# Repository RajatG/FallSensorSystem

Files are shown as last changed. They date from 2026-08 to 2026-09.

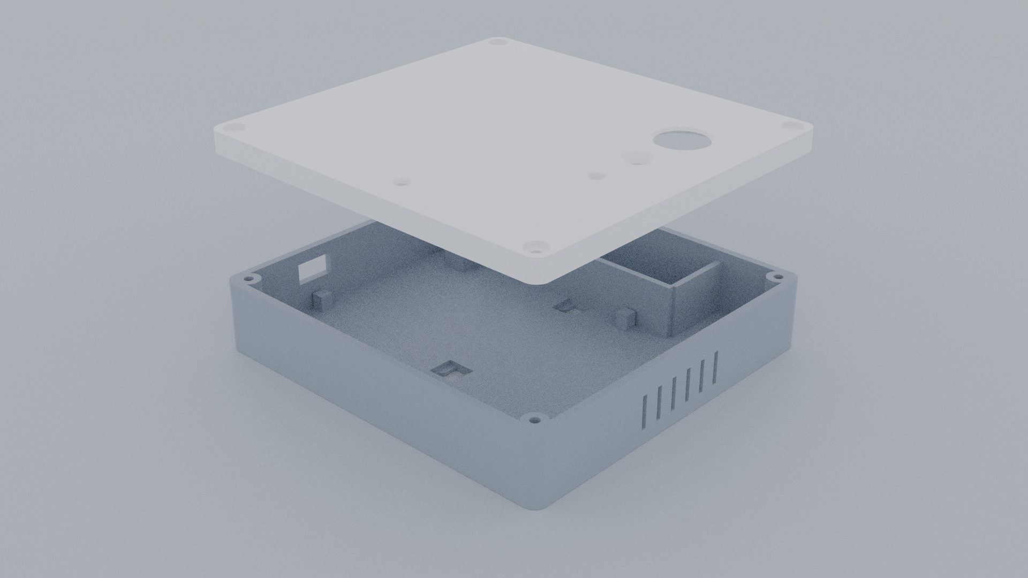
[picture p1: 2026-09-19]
enclosure/fall_sensor_enclosure_exploded.png

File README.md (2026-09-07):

# Fall Sensor System (IoT Firmware, KiCad PCB Hardware & Android Mobile App)

An ultra-low-power, dual-radar fall detection and room occupancy monitoring system engineered for ceiling and wall mounting with battery autonomy.

---

## 📁 Repository Overview

```
├── firmware/                        # Microcontroller & Radar Firmware
│   ├── fall_sensor_esp32_C1001_v1/  # ESP32 Firmware for C1001 60GHz Radar (v4.23)
│   ├── fall_sensor_esp32_ld2410_v1/ # ESP32 Firmware for LD2410 24GHz Radar (v4.23)
│   ├── fall_attiny_v1/              # ATtiny85 Low-Power Wake Sentinel (v4.8)
│   └── fall_attiny_mic_debug/       # ATtiny85 MIC Hardware Debug Utility
│
├── hardware/                        # KiCad 10.0 PCB & Schematic Files
│   ├── fall_sensor.kicad_sch        # Main System Schematic
│   ├── fall_sensor.kicad_pcb        # 2-Layer PCB Layout
│   ├── fall_sensor.kicad_pro        # KiCad Project Configuration
│   ├── FallSensor.kicad_sym     # Custom Symbol Library
│   ├── FallSensor.pretty/       # Custom Footprint Library
│   └── export/
│       ├── fall_sensor_gerbers.zip  # Production Gerber & Drill Package (JLCPCB/PCBWay)
│       └── pdf/                     # Printable Documentation (See hardware/export/pdf/README.md)
│           ├── fall_sensor_pcb_front_and_back_A4.pdf  # 1:1 True Scale Paper Testing Sheet
│           ├── fall_sensor_schematic_A4_printable.pdf # Printable A4 Schematic
│           ├── assembly/            # Top & Bottom Assembly Drawings
│           ├── layers/              # Top & Bottom Copper Layer Plots
│           └── schematic/           # Full-Size A3 Engineering Schematic
│
├── enclosure/                       # 3D Printed Wall-Mount Enclosure (v2.1 Square)
│   ├── fall_sensor_enclosure_base.stl # Base Mount with 18650 Battery Bay & PCB Standoffs
│   ├── fall_sensor_enclosure_lid.stl  # Front Cover with Apertures & Alignment Lip
│   ├── build_square_enclosure.py      # Parametric Blender Python CAD Script (v2.1)
│   ├── fall_sensor_enclosure.blend    # Master Blender CAD Project & Studio Renders
│   └── README.md                      # Mechanical Specifications & Slicer Guide
│
├── mobile_app/                      # Android Companion App (Jetpack Compose)
│   ├── app/                         # Source Code supporting C1001 & LD2410 Flavors
│   ├── build.gradle.kts
│   └── ...
│
└── docs/                            # Architectural Specs, Roadmaps & Engineering Docs (See docs/README.md)
    ├── README.md                    # Master Documentation Hub & Flow Map
    ├── Firmware_Architecture_and_Detection_Logic.md  # Complete Firmware Logic & 4-Layer Fall Pipeline
    ├── Master_4Stream_Roadmap_and_Recommendations.md # Comprehensive 4-Stream Status & Production Roadmap
    ├── PCB_Component_Connections_Verification.md     # Master 21-Component Netlist & Pinout Verification Guide
    ├── PCB_Component_Footprints_and_Dimensions.md    # Physical Dimensions, Drills & Pad Pitch Reference
    ├── SMD_BOM_Master_List.md       # Production SMD Component Master List (Rev B)
    ├── SMD_Hardware_Architecture.md # Power-path, Charger & Protection Circuitry Specs
    ├── C1001_Early_Exit_Analysis.md # Radar Optimization & Timing Breakdown
    └── ATtiny85_MIC_Analysis.md     # Sentinel Threshold & Acoustic Filter Specs
```

---

## ⚡ System Overview & Architecture

### What the System Is
The **Fall Sensor System** is a privacy-first, contactless room occupancy and fall detection device designed for elder care and clinical environments. It eliminates the need for cameras, audio-recording microphones, or wearable pendants.

### How it Works: The Staged-Wakeup Architecture
Operating mmWave radar continuously requires 60–120 mA, which would exhaust a battery in under two days. To achieve long battery life on a single 18650 cell, the system uses an **asymmetric staged-wakeup architecture**:

```
+-----------------------------------------------------------------------------------+
| 1. PASSIVE SENSING (Continuous ~35uA Draw)                                        |
|    - AM312 PIR watches for motion cone entry.                                     |
|    - LM393 acoustic sensor watches for mechanical floor impact shockwaves.       |
|    - ATtiny85 Sentinel debounces signals while ESP32 and Radar sleep.             |
+-----------------------------------------+-----------------------------------------+
                                          | Valid Motion or Thud Pulse
                                          v
+-----------------------------------------------------------------------------------+
| 2. RADAR VERIFICATION SNAPSHOT (2.5s - 4.0s Window)                               |
|    - ESP32 wakes from deep sleep and gates Radar power via MOSFET switch.         |
|    - mmWave Radar measures distance, target velocity, and floor-level coordinates.|
+-----------------------------------------+-----------------------------------------+
                                          |
                      +-------------------+-------------------+
                      |                                       |
              [ Normal Upright Motion ]               [ Confirmed Fall ]
                      |                                       |
                      v                                       v
+---------------------------------------------+ +-----------------------------------+
| 3. SMART EARLY EXIT                         | | 4. IMMEDIATE ALERTING             |
|    - Target confirmed standing/walking.     | |    - Red Fall Siren LED activates.|
|    - Radar cuts power at 2.5s - 4.0s.       | |    - BLE alert packet transmitted |
|    - BLE occupancy status updated.          | |      to Android caregiver app.    |
|    - ESP32 returns to deep sleep (<15uA).   | |    - Persists until recovery or   |
|      (Saves ~90% energy per event)          | |      manual sync button reset.    |
+---------------------------------------------+ +-----------------------------------+
```

---

## 📦 Engineering Streams & Subunit Documentation

The system is organized into four self-contained, documented engineering streams:

| Stream | Subunit Directory | Key Deliverables & Documentation |
|---|---|---|
| **⚡ Firmware** | [`firmware/`](firmware/README.md) | ESP32 C1001 & LD2410 drivers, ATtiny85 wake sentinel, v4.23 Gradual Posture Collapse detection, and flashing guides. |
| **🔌 Hardware (PCB)** | [`hardware/`](hardware/README.md) | KiCad 10.0 schematics, 2-layer PCB ($100 \times 80\text{ mm}$), pin mapping table, Gerbers, and 1:1 scale printable test sheets. |
| **🖨️ 3D Enclosure** | [`enclosure/`](enclosure/README.md) | v2.1 Square CAD model ($116.8 \times 110.8 \times 31.4\text{ mm}$), 18650 battery cradle, STL meshes, slicer settings, and photorealistic renders. |
| **📱 Mobile App** | [`mobile_app/`](mobile_app/README.md) | Android companion application (Jetpack Compose, Kotlin, BLE GATT), telemetry parser, and build flavor instructions. |
| **📚 Documentation** | [`docs/`](docs/README.md) | Master documentation hub, 4-layer fall logic specification, radar early exit analysis, acoustic sensitivity analysis, and SMD Rev B migration roadmap. |

---

## 🚀 Quick Manufacturing & Test Links

* **PCB Fabrication Gerbers:** [`hardware/export/fall_sensor_gerbers.zip`](hardware/export/fall_sensor_gerbers.zip) (Ready for JLCPCB/PCBWay upload).
* **1:1 Scale Paper Test Sheet:** [`hardware/export/pdf/fall_sensor_pcb_front_and_back_A4.pdf`](hardware/export/pdf/fall_sensor_pcb_front_and_back_A4.pdf) (For physical component fitting).
* **3D Printable STLs:** [`enclosure/fall_sensor_enclosure_base.stl`](enclosure/fall_sensor_enclosure_base.stl) and [`enclosure/fall_sensor_enclosure_lid.stl`](enclosure/fall_sensor_enclosure_lid.stl).
* **1:1 Scale 3D PCB Test Plate:** [`enclosure/fall_sensor_pcb_dummy.stl`](enclosure/fall_sensor_pcb_dummy.stl) (True KiCad 3D mesh with all 186 through-hole drill cutouts for physical pin-alignment and base cavity test-fitting).

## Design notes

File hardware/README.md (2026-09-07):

# 🔌 Hardware CAD & PCB Engineering (KiCad 10.0)

This directory contains the complete electronic schematic and PCB design files for the Fall Sensor System prototype (Rev A).

---

## 📁 Hardware Files

| File / Folder | Type | Description |
|---|:---:|---|
| **[`fall_sensor.kicad_sch`](fall_sensor.kicad_sch)** | Schematic | Main system schematic in KiCad 10 format. |
| **[`fall_sensor.kicad_pcb`](fall_sensor.kicad_pcb)** | PCB Layout | 2-layer, $100.00 \times 80.00\text{ mm}$ printed circuit board layout. |
| **[`fall_sensor.kicad_pro`](fall_sensor.kicad_pro)** | Project Config | KiCad project workspace and design rules. |
| **[`FallSensor.kicad_sym`](FallSensor.kicad_sym)** | Symbol Library | Custom schematic symbols for breakout modules. |
| **[`FallSensor.pretty/`](FallSensor.pretty/)** | Footprint Library | Custom PCB footprints for daughterboards and sensors. |
| **[`export/`](export/)** | Production Files | Manufacturing Gerbers and printable PDF packages. |

---

## 📐 PCB Specifications

* **Board Dimensions:** $100.00\text{ mm} \times 80.00\text{ mm}$
* **Layer Count:** 2-Layer FR4 ($1.6\text{ mm}$ thickness, $1\text{ oz}$ / $35\mu\text{m}$ copper)
* **Design Rule Status:** **0 DRC Errors, 0 Unconnected Nets**
* **Power Architecture:** Dual switched rails (Protected Li-Ion Battery $\rightarrow$ 5.0V Boost $\rightarrow$ 3.3V Step-Down).
* **Radar Gating:** High-side/low-side N-Channel MOSFET load switch controlled via GPIO 27.

---

## 📌 Microcontroller Pinout & Net Mapping

### ESP32 DevKit V1 (30-Pin) Net Connections
| Pin # | Label | Connected Net | Hardware Destination & Role |
|:---:|---|---|---|
| **1** | `3V3` | `+3V3` | Regulated 3.3V power input from U7 buck converter |
| **5** | `GPIO34` | `/BATT_ADC` | Midpoint of 100kΩ/100kΩ battery sensing divider |
| **8** | `GPIO33` | `Net-(U1-GPIO33)` | Tactile Sync & Alarm Clear Button (`SW1`) |
| **9** | `GPIO25` | `/PRESENCE` | C1001 radar hardware presence flag (`OUT1`) |
| **10** | `GPIO26` | `/FALL` | C1001 radar hardware fall detection flag (`OUT2`) |
| **11** | `GPIO27` | `/RADAR_EN` | Load switch gate control (energizes radar power rail) |
| **14** | `GND` | `GND` | Common system ground plane |
| **15** | `GPIO13` | `/PIR_WAKE` | Motion wake interrupt from ATtiny85 Sentinel (`PB2`) |
| **19** | `GPIO19` | `Net-(U1-GPIO19)` | Status Fall Alarm LED (`D1`) via 270Ω resistor |
| **26** | `GPIO17` | `/RADAR_RX` | Hardware UART RX $\leftarrow$ C1001 radar TX |
| **27** | `GPIO16` | `/RADAR_TX` | Hardware UART TX $\rightarrow$ C1001 radar RX |
| **28** | `GPIO4` | `/MIC_WAKE` | Acoustic impact wake interrupt from ATtiny85 Sentinel (`PB0`) |

### ATtiny85 Sentinel Pin Mapping
| Pin # | Label | Connected Net | Hardware Destination & Role |
|:---:|---|---|---|
| **2** | `PB4` | `Net-(U2-P4)` | Digital acoustic trigger input from LM393 (`DO`) |
| **5** | `PB1` | `Net-(PIR1-OUT)` | Digital motion trigger input from AM312 PIR (`OUT`) |
| **6** | `PB0` | `/MIC_WAKE` | Active-HIGH 50ms wake pulse to ESP32 `GPIO4` |
| **4** | `PB2` | `/PIR_WAKE` | Active-HIGH 50ms wake pulse to ESP32 `GPIO13` |
| **7** | `GND` | `GND` | Common ground |
| **8** | `VIN` | *Unconnected* | Bypassed (Digispark onboard regulator not used) |
| **9** | `5V/VCC` | `+3V3` | Regulated 3.3V power input from U7 buck converter |

---

## 📦 Manufacturing & Test Deliverables

* **Gerber Package:** [`export/fall_sensor_gerbers.zip`](export/fall_sensor_gerbers.zip) — Ready for direct upload to JLCPCB, PCBWay, or OSH Park.
* **1:1 True Scale Paper Testing Sheet:** [`export/pdf/fall_sensor_pcb_front_and_back_A4.pdf`](export/pdf/fall_sensor_pcb_front_and_back_A4.pdf) — Verified 1:1 A4 sheet with 10.0 cm calibration ruler for physical component fit-testing.
* **Assembly & Layer Drawings:** See [`export/pdf/README.md`](export/pdf/README.md) for top/bottom silkscreen and layer plots.

---

## 📖 Detailed Engineering References
* Complete 21-component netlist and verification tables: [`../docs/PCB_Component_Connections_Verification.md`](../docs/PCB_Component_Connections_Verification.md)
* Physical package outlines, drill sizes, and pad-to-pad pitches: [`../docs/PCB_Component_Footprints_and_Dimensions.md`](../docs/PCB_Component_Footprints_and_Dimensions.md)
* Production SMD Component Master List (Rev B): [`../docs/SMD_BOM_Master_List.md`](../docs/SMD_BOM_Master_List.md)

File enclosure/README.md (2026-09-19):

# 🖨️ Fall Sensor System - Wall-Mount 3D Printed Enclosure

This directory contains the complete **3D CAD engineering stream** for the Wall-Mounted Enclosure of the Fall Sensor System.

---

## 📁 Files in this Directory

| File | Type | Description |
|---|---|---|
| [`fall_sensor_enclosure_base.stl`](fall_sensor_enclosure_base.stl) | 3D Mesh (STL) | **Base Mount (v2.1)**: Integrated 79.5mm 18650 battery compartment with wire notch, retaining end-wall, open PIR alcove, 5mm PCB shelf posts, 4 corner screw bosses, rear wall-mount keyholes, USB-C port, and side ventilation louvers. |
| [`fall_sensor_enclosure_lid.stl`](fall_sensor_enclosure_lid.stl) | 3D Mesh (STL) | **Front Cover (v2.1)**: Balanced square profile with 4 corner screw guide pillars, 4 downward PCB clamping tabs (3.9mm), PIR dome opening, Radar RF thin window, Mic port, Fall LED hole, Sync button pinhole, and side ventilation. |
| [`fall_sensor_enclosure_assembled_hero.png`](fall_sensor_enclosure_assembled_hero.png) | High-Res Render | Assembled square enclosure hero view in locked high-contrast studio scene. |
| [`fall_sensor_enclosure_exploded.png`](fall_sensor_enclosure_exploded.png) | High-Res Render | Exploded assembly view showing floating lid with visible downward clamp tabs, base alignment, and internal features. |
| [`fall_sensor_enclosure_studio.png`](fall_sensor_enclosure_studio.png) | High-Res Render | Studio side-by-side open view showing both internal cavities (battery bay and shelf posts on left; clamp tabs and radar pocket on right). |
| [`fall_sensor_enclosure_wallmount.png`](fall_sensor_enclosure_wallmount.png) | High-Res Render | Rear perspective view showing the 50mm spaced wall-mounting keyhole slots. |
| [`fall_sensor_pcb_dummy.stl`](fall_sensor_pcb_dummy.stl) | 3D Mesh (STL) | **1:1 Scale Test-Fit PCB ($100.00 \times 80.00 \times 1.51\text{ mm}$)**: Exact 3D mesh exported directly from KiCad 10 with all 186 through-hole pin and via drill cutouts (ESP32, ATtiny85, TP4056, C1001 Radar, passives, etc.) for physical hole-alignment and base cavity test-fitting. |
| [`fall_sensor_enclosure.blend`](fall_sensor_enclosure.blend) | Blender CAD | **Master Blender 2.91+ CAD project**: Exact parametric Boolean geometry, Cycles lighting, materials, and automated multi-view render pipeline. |

---

## 📐 Enclosure Dimensions & Mechanical Specifications (v2.2 Slim Ceiling-Mount)

* **External Dimensions:** `116.8 mm (Width) × 110.8 mm (Depth) × 28.0 mm (Total Height)`
* **Form Factor Aspect Ratio:** `1.05 : 1` — **Balanced modern square form factor**.
* **Base Height:** `21.5 mm` (Floor thickness: `2.4 mm`, Internal depth: `19.1 mm` securely cradling the 18650 battery holder and PCB assembly).
* **Lid Height:** `6.5 mm` low-profile room-facing faceplate (Ceiling thickness: `2.4 mm`, Internal depth: `4.1 mm`).
* **Total Enclosure Assembled Height:** `28.0 mm` (shaves 3.4mm off previous bulk, leaving strictly what is required).
* **Outer Wall Thickness:** `2.4 mm` throughout for high structural rigidity and impact resistance.
* **Internal Battery Compartment:** Dedicated `74.0 mm (W) × 22.0 mm (D) × 16.0 mm (H)` cradle ($X$ in $[-42.0, +32.0]\text{ mm}$) with a rigid vertical retaining end-wall and a $8.0 \times 6.0\text{ mm}$ wire pass-through notch, cleanly fitting standard 18650 battery holders.
* **Open PIR Sensor Alcove:** The region to the right of the battery retaining wall ($X = +32.0$ to $+56.0\text{ mm}$) is **100% open** to the main PCB cavity, allowing the AM312 PIR sensor to extend freely without any wall interference.
* **Internal PCB Compartment:** `102.0 mm × 82.0 mm` pocket providing a snug `1.0 mm` perimeter clearance around the standard $100 \times 80\text{ mm}$ PCB.
* **Radar RF Isolation Chamber:** Dedicated $10.0\text{ mm}$ right-side expansion chamber ($X = +45.0$ to $+56.0\text{ mm}$) providing complete dielectric isolation and free-air clearance for the overhanging C1001 60GHz radar antenna patches.

---

## 🔒 PCB Clamping Architecture (Zero-Screw Sandwich Clamp)

The enclosure utilizes a **zero-screw perimeter clamping architecture**, eliminating the need for dedicated screw holes through the PCB and maximizing usable copper routing area:

```
  ┌─────────────────────────────────────────────────────────┐  Lid Ceiling (Z = 29.0 mm)
  │                     Lid Cavity                          │
  │     [Headroom: 20.0 mm clear space above PCB]           │
  │                                                         │
  │   [4x PCB Downward Clamp Tabs]                          │  Lid Rim (Z = 13.0 mm)
  │   └── Depth: 3.9 mm ───┐                                │
  └───┬────────────────────┼────────────────────────────────┘
      ▼                    ▼  (Snug Downward Clamping)
  ═══════════════════════════════════════════════════════════  PCB Top Surface (Z = 9.0 mm)
              PCB (FR4 Core, Thickness = 1.6 mm)
  ═══════════════════════════════════════════════════════════  PCB Bottom Surface (Z = 7.4 mm)
      ▲                    ▲  (Solid Upward Support)
  ────┴────────────────────┴─────────────────────────────────
  │   └── 4x Perimeter Shelf Posts (Height: 5.0 mm)         │
  │                                                         │
  │   [Solder Clearance: 5.0 mm air gap to floor]           │
  └─────────────────────────────────────────────────────────┘  Base Floor (Z = 0.0 to 2.4 mm)
```

1. **Underside Support (Base Shelf Posts):**
   * 4 monolithic perimeter shelf posts ($4.0 \times 4.0\text{ mm}$, height `5.0 mm`) molded directly into the base floor.
   * Located at certified copper-free and pin-free keepout zones: Left `(-53.5, -43.0)`, Right `(+43.5, -21.0)`, Bottom `(+23.0, -50.5)`, Top `(+23.0, +26.5)`.
   * Provides a generous `5.0 mm` air gap above the floor, completely clear of all through-hole solder pins and joints.
2. **Top Clamping (Lid Downward Tabs):**
   * 4 monolithic downward clamp tabs ($4.0 \times 4.0\text{ mm}$, height `3.9 mm`) molded into the lid ceiling directly over the base shelf posts.
   * Strategically positioned in certified open keepout zones completely clear of all headers, modules, and components (Left between SW2 & BT1; Right between D1 & RADAR1; Bottom between SW1 & RADAR1; Top between C8 & PIR1).
   * When the 4 lid screws are fastened, the tabs apply a firm `0.1 mm` compression onto the bare PCB perimeter, locking the board rigidly with **zero vertical rattle** and **zero lateral play**.

---

## 🔍 Sensor Openings & Port Map

The enclosure apertures match the physical PCB component footprint coordinates down to the sub-millimeter:

```
+-------------------------------------------------------------------------+
|      [ 18650 Battery Cradle (79.5mm) ]       |   [ Open PIR Alcove ]    |
+----------------------------------------------+--------------------------+
|                                              [ PIR Dome Aperture ]      |
|                                                 (Dia: 12.0 mm)          |
|                                                                         |
|                       [ Mic Acoustic Port ]                             |
|                           (Dia: 3.0 mm)                                 |
|                                              [ Status Fall LED ]        |
|    [USB-C Port]                                 (Dia: 3.2 mm)           |
|   (12.0x6.5mm, Z=14.5mm)                                                |
|                                              [ C1001 Radar RF Window ]  |
|   (Solid Left Wall,     [ Sync Button ]           (Internal Pocket,     |
|    Internal Jumper)      (Dia: 3.5 mm)             1.0 mm Membrane)     |
+-------------------------------------------------------------------------+
        ▲                                              ▲
    LEFT WALL                                      RIGHT SIDE
```

| Aperture / Port | Location / Face | Coordinates `(ex, ey)` | Dimensions | Matching Hardware Component |
|---|---|:---:|---|---|
| **PIR Fresnel Dome** | Top Lid Face | `(+37.50, +23.39) mm` | $\varnothing 12.0\text{ mm}$ hole + **$\mathbf{\varnothing 17.0\text{ mm}}$ $45^\circ$ optical flare** | `PIR1` (AM312 PIR motion sensor lens, unobstructed wide-angle doorway view) |
| **LM393 Mic Sound Port** | Top Lid Face | `(+37.50, +5.00) mm` | $\varnothing 4.5\text{ mm}$ port + **$\mathbf{\varnothing 9.5\text{ mm}}$ $45^\circ$ acoustic horn** | `U5` (Acoustic collector funnels wide-angle room sounds into electret capsule) |
| **Status / Fall Alarm LED** | Top Lid Face | `(+37.50, -11.00) mm` | $\varnothing 3.2\text{ mm}$ hole + **$\mathbf{\varnothing 4.8\text{ mm}}$ $45^\circ$ diffuser flare** | `D1` (3mm through-hole LED, wide-angle ceiling visibility) |
| **C1001 Radar RF Window** | Inside Lid Ceiling | `(+36.50, -34.00) mm` | $24.0 \times 24.0\text{ mm}$ pocket ($1.0\text{ mm}$ membrane) | `RADAR1` (RF transparent window over 60GHz antenna) |
| **ESP32 Contact Boss** | Inside Lid Ceiling | `(+2.00, -19.00) mm` | $14.0 \times 14.0 \times 3.4\text{ mm}$ boss | `U1` (Clamps metal RF shield against roof sag with ~0.5mm EVA gap) |
| **Sync / Reset Button** | Top Lid Face | `(+5.50, -45.50) mm` | $\varnothing 3.5\text{ mm}$ hole + **$\mathbf{\varnothing 5.0\text{ mm}}$ $45^\circ$ funnel chamfer** | `SW1` (6x6x8mm tactile push button access via pen/pin) |
| **USB-C Charging Cutout** | Left Base Wall | `(-58.40, -25.00) mm` | $12.0 \times 6.5\text{ mm}$ slot ($Z = 14.5\text{ mm}$) | `U4` (TP4056 Type-C charger elevated on 2.5mm male header spacer) |
| **Power Switch** | Internal on PCB | *N/A* | *No external cutout* (Solid wall) | `SW2` (Standard 2.54mm header pin jumper cap / shunt) |
| **Cooling Vents** | Right Base Wall | $Y \in [-15, +15]\text{ mm}$ | 6x vertical slots ($1.6 \times 10.0\text{ mm}$) | Convective thermal dissipation for MT3608 & TP4056 |

---

## 🧱 Wall Mounting Guidelines

* **Mounting Method:** Two rear **Keyhole Hanging Slots** spaced **$50.0\text{ mm}$ apart**.
  * Entry hole: $\varnothing 8.5\text{ mm}$ (fits standard drywall screw heads up to $\varnothing 8.0\text{ mm}$).
  * Slide slot: $4.5\text{ mm}$ wide (accepts standard #6, #8, M3.5, or M4 screws).
  * Retaining lip: $1.4\text{ mm}$ recessed shelf for anti-shake retention.
* **Wall Installation:**
  1. Drive two screws into the wall at standard wall height ($2.4\text{ m} - 2.7\text{ m}$ / 8 to 9 feet), spaced **$50.0\text{ mm}$ vertically**, leaving $\approx 2.5\text{ mm}$ of screw head exposed.
  2. Align the keyholes with the screw heads and push downwards to lock into place.
  3. The unit can be unhooked in seconds for USB-C recharging or battery replacement.

---

## 🖨️ 3D Printing Recommended Slicer Settings

| Slicer Setting | Recommended Value | Notes |
|---|---|---|
| **Filament Material** | **PETG** (or ABS/ASA; PLA for indoor prototypes) | PETG provides superior heat resistance and impact toughness. |
| **Layer Height** | `0.20 mm` (Quality/Standard) | Optimum balance of fine feature resolution and layer strength. |
| **Wall Loops / Perimeters** | `4 loops` ($1.6\text{ mm}$ thickness) | Essential for solid screw boss pillars and durable corner threads. |
| **Top & Bottom Solid Layers** | `5 layers` ($1.0\text{ mm}$) | Ensures watertight ceiling and rigid bottom base plate. |
| **Infill Density & Pattern** | `20% - 25% Gyroid` or `Grid` | Gyroid provides isotropic structural strength. |
| **Supports** | **Minimal (Base build plate only)** | Only a small support tree inside the horizontal USB-C bridge. |
| **Build Plate Orientation** | **Base:** Bottom face flat on bed<br>**Lid:** Top face flat on bed | **Zero supports required on the lid outer face!** |

---

## 🔩 Hardware Bill of Materials (Assembly Screws)

| Application | Quantity | Screw Specification | Recommended Product / Notes |
|---|---|---|---|
| **Enclosure Lid Closure** | **4x** | **`M3 × 25 mm` Hex Allen CSK** (Countersunk Flat Head) | [EasyMech M3 × 25mm Hex CSK](https://robu.in/product/ntl-easymech-m3-x-25mm-hex-allen-csk-high-tensile109-black-oxide-screw-dia-3mm-length-25mm). Passes through 18.4mm lid pillars and grips 6.6mm into base bosses. Sits flush with top face. |
| **PCB Mounting** | **0x** | *None required* | PCB is rigidly clamped between the base shelf posts and lid downward tabs. |
| **Wall Mounting** | **2x** | Standard drywall screws (#6 or #8) | Head diameter $\le 8.0\text{ mm}$, shaft $\le 4.2\text{ mm}$, with wall anchors. |

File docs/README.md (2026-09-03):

# 📚 Fall Sensor System — Master Documentation Hub

Welcome to the technical engineering documentation for the Fall Sensor System. This directory contains the complete architectural specifications, firmware state machines, hardware verification guides, and production roadmaps.

---

## 🧭 Complete Documentation Flow

```
                                  [ Root README ]
                                         │
                 ┌───────────────────────┴───────────────────────┐
                 │                                               │
    [ 1. System Roadmap & Specs ]                  [ 2. Firmware Architecture ]
    Master_4Stream_Roadmap_and_                   Firmware_Architecture_and_
    Recommendations.md                            Detection_Logic.md
                 │                                               │
        ┌────────┴────────┐                             ┌────────┴────────┐
        │                 │                             │                 │
  [ SMD Architecture ] [ SMD BOM ]             [ Radar Early Exit ]  [ MIC Sentinel ]
  SMD_Hardware_        SMD_BOM_                C1001_Early_Exit_     ATtiny85_MIC_
  Architecture.md      Master_List.md          Analysis.md           Analysis.md
                 │
    [ 3. PCB Hardware Verification ]
    ├── PCB_Component_Connections_Verification.md
    └── PCB_Component_Footprints_and_Dimensions.md
```

---

## 📑 Document Catalog

### 1. 📋 System Roadmaps & Product Architecture
* **[`Master_4Stream_Roadmap_and_Recommendations.md`](Master_4Stream_Roadmap_and_Recommendations.md)**  
  *Executive summary of all 4 engineering streams (Firmware, PCB Hardware, 3D Enclosure, Android App), including current completion percentages, milestones, and the complete Rev B SMD production transition plan.*
* **[`SMD_Hardware_Architecture.md`](SMD_Hardware_Architecture.md)**  
  *Production hardware architecture: discrete TP4056 charging, MT3608 boost, DW01A battery protection, USBLC6-2SC6 ESD suppression, power-path PMIC, and thermal cutoff specs.*
* **[`SMD_BOM_Master_List.md`](SMD_BOM_Master_List.md)**  
  *Complete Bill of Materials for automated SMT pick-and-place assembly (LCSC / JLCPCB part numbers).*

---

### 2. 🧠 Firmware & Sensor Signal Processing
* **[`Firmware_Architecture_and_Detection_Logic.md`](Firmware_Architecture_and_Detection_Logic.md)**  
  *Complete end-to-end firmware guide: Deep sleep power states, wakeup interrupts, radar warmup and early exit sequence, the 4-layer fall detection pipeline (Acoustic $\rightarrow$ Dynamic $\rightarrow$ Floor Level $\rightarrow$ Gradual Posture Collapse), and BLE telemetry protocol.*
* **[`C1001_Early_Exit_Analysis.md`](C1001_Early_Exit_Analysis.md)**  
  *In-depth timing breakdown of C1001 60GHz UART loop latency, double-call bug fixes, and the 2.5s early exit logic that yields up to ~90% power savings.*
* **[`ATtiny85_MIC_Analysis.md`](ATtiny85_MIC_Analysis.md)**  
  *Acoustic impact sensitivity analysis: ATtiny85 $V_{IH}$ logic threshold matching, LM393 open-collector pull-up configurations, and hardware interrupt debounce.*

---

### 3. 🔌 Hardware Verification & PCB Guides
* **[`PCB_Component_Connections_Verification.md`](PCB_Component_Connections_Verification.md)**  
  *Master netlist and pinout verification guide for all 21 components on the Rev A PCB.*
* **[`PCB_Component_Footprints_and_Dimensions.md`](PCB_Component_Footprints_and_Dimensions.md)**  
  *Complete physical package dimensions, drill hole diameters, and pad-to-pad pitches for physical prototyping.*

---

## 🖨️ Fabrication & Printable Deliverables

* **PCB 1:1 Scale Paper Test Sheet:** [`../hardware/export/pdf/fall_sensor_pcb_front_and_back_A4.pdf`](../hardware/export/pdf/fall_sensor_pcb_front_and_back_A4.pdf)
* **Production Gerber Package:** [`../hardware/export/fall_sensor_gerbers.zip`](../hardware/export/fall_sensor_gerbers.zip)
* **3D Printed Enclosure STLs & CAD:** [`../enclosure/`](../enclosure/)

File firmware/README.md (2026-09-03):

# ⚡ Microcontroller & Sensor Firmware

This directory contains the production firmware for the dual-processor fall detection pipeline, supporting both 60GHz ceiling-mounted and 24GHz wall-mounted radar variants.

---

## 📁 Firmware Modules

| Directory | Target Hardware | Role | Core Functions |
|---|---|---|---|
| **[`fall_sensor_esp32_C1001_v1/`](fall_sensor_esp32_C1001_v1/)** | ESP32 DevKit V1 (30-pin) | Main Controller (Ceiling) | C1001 60GHz UART radar driver, 2.5s warmup, smart early exit, 4-layer fall detection (including v4.23 Gradual Posture Collapse), BLE GATT telemetry server, deep sleep management. |
| **[`fall_sensor_esp32_ld2410_v1/`](fall_sensor_esp32_ld2410_v1/)** | ESP32 DevKit V1 (30-pin) | Main Controller (Wall) | Hi-Link LD2410 24GHz radar driver, moving/stationary gate state machine, BLE GATT server, deep sleep management. |
| **[`fall_attiny_v1/`](fall_attiny_v1/)** | ATtiny85 (Digispark) | Ultra-Low-Power Sentinel | Continuous ~30µA motion/acoustic monitor. Debounces AM312 PIR and LM393 sound detector, generating 50ms wake pulses to ESP32 EXT1 pins. |
| **[`fall_attiny_mic_debug/`](fall_attiny_mic_debug/)** | ATtiny85 (Digispark) | Hardware Diagnostic Tool | Diagnostic utility with onboard LED blink codes to verify acoustic comparator logic levels ($V_{IH}$) on PB4. |

---

## ⚙️ Compilation & Flashing Instructions

### 1. ESP32 Firmware (`C1001` or `LD2410`)
* **Environment:** Arduino IDE 2.x or PlatformIO
* **Board:** `DOIT ESP32 DEVKIT V1`
* **Partition Scheme:** `Default 4MB with spiffs (1.2MB APP / 1.5MB SPIFFS)`
* **Dependencies:**
  * `DFRobot_HumanDetection` (for C1001)
  * `LD2410` by ncmreynolds (for LD2410)
  * Standard ESP32 core libraries (`BLEDevice`, `BLEServer`, `BLEUtils`, `BLE2902`, `WiFi`, `ArduinoOTA`)
* **Flash Settings:** Upload Speed: `921600`, Flash Frequency: `80MHz`.

### 2. ATtiny85 Sentinel Firmware
* **Environment:** Arduino IDE 2.x with `ATTinyCore` by SpenceKonde
* **Board:** `ATtiny85 (Micronucleus / Digispark)`
* **Clock Source:** `1 MHz (Internal)` — *Ensures minimum active current draw ($< 250\mu\text{A}$ active, $< 5\mu\text{A}$ deep sleep)*.
* **Upload:** Plug Digispark into USB only when prompted by the Micronucleus uploader.

---

## 📖 In-Depth Technical References
* Detailed state machines, timing diagrams, and fall algorithms: [`../docs/Firmware_Architecture_and_Detection_Logic.md`](../docs/Firmware_Architecture_and_Detection_Logic.md)
* C1001 Radar UART optimization and early exit benchmarks: [`../docs/C1001_Early_Exit_Analysis.md`](../docs/C1001_Early_Exit_Analysis.md)
* ATtiny85 acoustic comparator voltage thresholds: [`../docs/ATtiny85_MIC_Analysis.md`](../docs/ATtiny85_MIC_Analysis.md)

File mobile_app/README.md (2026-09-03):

# 📱 Fall Sensor Mobile App (Android Companion)

An Android companion application built for caregivers and clinicians to monitor fall events, room occupancy, and device health over Bluetooth Low Energy (BLE).

---

## 🛠️ Architecture & Tech Stack

* **Language:** 100% Kotlin
* **UI Framework:** Jetpack Compose + Material 3 (Dark Theme)
* **Architecture:** MVVM (Model-View-ViewModel) with Kotlin Coroutines & `StateFlow`
* **Connectivity:** Android Bluetooth Low Energy (GATT Client) with automatic background reconnection and state recovery.

---

## 🏷️ Product Flavors

The Gradle build configuration supports two hardware target flavors:

| Flavor | Target Sensor | BLE Scan Filter | Description |
|---|---|---|---|
| **`c1001`** | DFRobot C1001 (60 GHz) | `FallSensor_C1001*` | Ceiling-mounted sensor UI with target distance-to-ceiling display and human presence flags. |
| **`ld2410`** | Hi-Link LD2410 (24 GHz) | `FallSensor_LD2410*` | Wall-mounted sensor UI with moving/stationary gate distance metrics. |

---

## ⚡ Core Features

1. **Real-Time Telemetry Dashboard:**
   * Live battery voltage and dynamic discharge curve lifetime forecasting.
   * Uptime counter (`Xh Ym Zs`).
   * Room occupancy status (`OCCUPIED` vs `VACANT`) with 4 animated sensor indicators.
2. **Instant Fall Alert Display:**
   * High-visibility alert banners triggered immediately upon receiving `ALERT: FALL DETECTED` packets.
   * Visual reset and disarm controls via the BLE `RESET` command.
3. **Caregiver Configuration & Diagnostics:**
   * **Room Height Configuration:** Send `SET:HEIGHT:<cm>` to calibrate floor threshold in the sensor's non-volatile memory.
   * **Telemetry Logging Toggle:** `LOG_ON` and `LOG_OFF` commands to inspect raw 100ms radar gate packets without draining battery during normal use.
   * **Over-the-Air Update Trigger:** `OTA_ON` command to put the sensor into firmware update mode.

---

## 📡 BLE GATT Specifications

* **Service UUID:** `4fafc201-1fb5-459e-8fcc-c5c9c331914b`
* **Telemetry Characteristic UUID:** `beb5483e-36e1-4688-b7f5-ea07361b26a8` (Read, Write, Notify)

---

## 🚀 Building & Running

### Requirements
* Android Studio Iguana / Jellyfish (or newer)
* Android SDK 34 (Android 14)
* Minimum SDK: Android 26 (Android 8.0 Oreo)

### Build Commands
```bash
# Build C1001 Ceiling Flavor Debug APK
./gradlew assembleC1001Debug

# Build LD2410 Wall Flavor Debug APK
./gradlew assembleLd2410Debug
```
Output APKs will be generated in `app/build/outputs/apk/<flavor>/debug/`.

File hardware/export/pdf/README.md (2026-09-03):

# 📄 Printable PDFs & Manufacturing Drawings

This directory contains the organized printable PDF packages for testing, assembly, and schematic review of the Fall Sensor PCB.

---

## 🌟 Essential Files (Root)

| File | Format | Description |
|---|:---:|---|
| **[`fall_sensor_pcb_front_and_back_A4.pdf`](fall_sensor_pcb_front_and_back_A4.pdf)** | **1:1 Vector PDF** | **Paper Testing Template**: Side-by-side Top and Bottom layers at exact 1:1 true CAD scale ($100.0 \times 80.0\text{ mm}$ board outlines) with precision 10.0 cm calibration ruler. |
| **[`fall_sensor_schematic_A4_printable.pdf`](fall_sensor_schematic_A4_printable.pdf)** | **A4 PDF** | **Printable Schematic**: Complete system schematic formatted to fit standard A4 paper for workbench reference. |
| **[`fall_sensor_pcb_front_and_back_A4.jpg`](fall_sensor_pcb_front_and_back_A4.jpg)** | High-Res Image | High-resolution 300 DPI preview of the 1:1 print sheet. |

---

## 📁 Subdirectories

### 1. `assembly/` — Fabrication & Component Placement
* **[`fall_sensor_pcb_top_assembly.pdf`](assembly/fall_sensor_pcb_top_assembly.pdf)**: Top layer silkscreen, component reference designators, and pin-1 markers for manual soldering.
* **[`fall_sensor_pcb_bottom_assembly.pdf`](assembly/fall_sensor_pcb_bottom_assembly.pdf)**: Bottom layer reference markings and test points.
* **[`fall_sensor_pcb_all_layers.pdf`](assembly/fall_sensor_pcb_all_layers.pdf)**: Complete multi-layer CAD drawing containing all copper and silkscreen layers.

### 2. `layers/` — Individual Copper Layers
* **[`fall_sensor_pcb_top_board_only.pdf`](layers/fall_sensor_pcb_top_board_only.pdf)**: Top copper traces (`F.Cu`), front silkscreen (`F.SilkS`), and board edge cuts (`Edge.Cuts`).
* **[`fall_sensor_pcb_bottom_board_only.pdf`](layers/fall_sensor_pcb_bottom_board_only.pdf)**: Bottom copper traces (`B.Cu`), bottom ground plane, and mirrored view for DIY toner-transfer or inspection.

### 3. `schematic/` — Full-Size Engineering Schematic
* **[`fall_sensor_schematic.pdf`](schematic/fall_sensor_schematic.pdf)**: Full-size standard A3 engineering schematic directly exported from KiCad 10 Eeschema.

---

> [!TIP]
> **Printing Instructions for 1:1 Accuracy:**
> When printing `fall_sensor_pcb_front_and_back_A4.pdf`, ensure your PDF viewer is set to **"Actual Size"** or **"Custom Scale: 100%"**. Never select "Fit to Printable Area". Verify accuracy using the 100 mm scale ruler at the bottom.

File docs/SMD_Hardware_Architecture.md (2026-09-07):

# Commercial SMD Hardware Architecture & Power Management Design

This guide outlines the transition from a prototype with breakout modules to a compact, production-ready **Surface Mount Device (SMD)** PCB design for the Fall Sensor system.

---

## 1. Complete SMD Component Migration List

Replacing breakout boards with discrete SMD ICs reduces board footprint by **up to 70%** while significantly increasing reliability and lowering unit BOM cost.

| Prototype Breakout Board | Component Function | Recommended Discrete SMD IC / Part | Package Type | Key Advantages |
|---|---|---|---|---|
| **ESP32 DevKit V1** | Main Microcontroller | **ESP32-WROOM-32E** (or ESP32-WROOM-32UE with U.FL antenna) | SMD Module (18x25.5mm) | Integrated RF shielding, FCC/CE certified, compact footprint. |
| **Digispark ATtiny85** | Sentinel Co-Processor | **ATtiny85-20SU** (or ATtiny45-10SU) | SOIC-8 (150mil) | Tiny 5x4mm IC, ultra-low power deep sleep (<1µA). |
| **TP4056 Charger Board** | 1S Li-Ion Charger | **TP4056** (or **TP4057** / **LTC4054**) | SOT-23-6 / SOP-8-PP | 1A linear charger IC with LED status pins. |
| **MT3608 Boost Board** | 3.7V to 5V Step-Up | **MT3608** (or **TPS61099** / **SX1308**) | SOT-23-6 | 1.2MHz high-efficiency boost IC. |
| **LM393 Sound Module** | Acoustic Thud Sensor | **LM393G** / **LM393LV** Dual Comparator + Electret Mic Capsule | SOIC-8 / 6mm Mic | Discrete SMD comparator + SMT electret mic. |
| **AM312 PIR Module** | Motion Detection | **AS312** (or **PIR sensor element + BISS0001 IC**) | SOT-23-6 / TO-5 | Compact surface-mount PIR sensor element. |
| **Load Switch Socket (U6)** | Radar Power Switch | **TPS22918DBVT** (or **BSS138** / **AO3400A**) | SOT-23-6 | High-efficiency load switch IC with integrated slew rate control. |
| **LM2596 Buck Module (U7)** | 5V to 3.3V Step-Down | **TLV75533PDBVR** (or **AMS1117-3.3**) | SOT-23-5 | Ultra-low Iq 3.3V LDO regulator replacing bulky prototype buck module. |
| **Power Switch SW2** | System Power Switch | **SS-12D00** / **SK-12D07** SMT Slide Switch | SMT 3-Pin | Low-profile surface-mount slide switch. |
| **Sync Button SW1** | Reset / BLE Button | **EVQ-P7A01K** 3x4mm SMT Tactile Switch | SMT 2-Pin | Soft-touch SMT push button. |
| **Passives (R1-R3, D1, 5 Caps)** | Resistors, LED, Caps | 0805 or 0603 SMD Resistors / 0805 LED / MLCC | 0805 / 0603 SMT | Standard SMT surface mount passives (C1, C3, C4, C7, C8). |

---

## 2. Essential Battery Protection & Professional Circuitry

A commercial battery-powered IoT device requires robust hardware protection to meet CE/FCC/UL safety standards:

```
[ USB-C Plug ] ---> [ USBLC6-2SC6 (ESD Protection) ]
                         |
                         v
[ P-MOSFET Reverse Polarity ] ---> [ TP4056 Charger IC ]
                                         |
                                         v
                     [ DW01A + FS8205A (Over-Charge / Over-Discharge PCM) ]
                                         |
                                         v
                              [ 3.7V Li-Ion Battery ]
```

### Essential Protection Components:
1. **Under-Voltage Lockout (UVLO / Over-Discharge Protection):**
   * **IC Combo:** **DW01A** (Protection Controller IC) + **FS8205A** (Dual N-Channel MOSFET in TSSOP-8).
   * **Function:** Automatically disconnects the battery if voltage drops below **2.8V** to prevent permanent cell damage or chemical swelling.
2. **Over-Charge Protection:**
   * Cuts off charging automatically at **4.25V ± 0.05V**.
3. **Over-Current & Short-Circuit Protection:**
   * DW01A detects short circuits and shuts off the dual MOSFET within microseconds if current exceeds ~3A.
4. **Reverse Polarity Protection:**
   * A **P-Channel MOSFET (e.g. AO3401A)** placed on the battery positive line prevents catastrophic component destruction if the battery leads are accidentally reversed during assembly.
5. **USB-C Input ESD Protection:**
   * **USBLC6-2SC6** (SOT-23-6) placed on VBUS and D+/D- lines protects sensitive electronics against 15kV static discharge when plugging in the USB cable.
6. **Thermal / NTC Thermistor Protection:**
   * Connecting a 10K NTC thermistor attached to the battery pack to the TEMP pin of the charger IC prevents charging if battery temperature is < 0°C or > 45°C.

---

## 3. Power Architecture Optimization: Breakout Modules vs. Integrated Power-Path Solutions

### Evaluating Combined Modules (J5019 / IP5306 / BQ24075)

While module boards like the **J5019** (combined TP4056 + MT3608) save wiring space, they suffer from a major design flaw known as **Lack of Power-Path Management**.

#### The "No Power-Path" Problem:
If you charge a battery while the ESP32 is drawing current from the same rail:
- The TP4056 charger cannot distinguish between battery charge current and system operating current.
- The charger fails to detect the 1/10th termination current threshold, causing the battery to **overcharge, overheat, or loop-charge continuously**.

```
❌ BAD (No Power-Path):
USB 5V ---> Charger ---> [ Battery + ESP32 Load (Shared Rail) ]  (Continuous loop charging)

✅ GOOD (Hardware Power-Path):
USB 5V ---> [ Power-Path Switch ] ---> ESP32 System Rail (Direct 5V)
                     |
                     +-------------> Charger ---> Battery (Isolated charging)
```

### Recommended Integrated Power Management ICs (PMICs):

1. **Texas Instruments BQ24075 (Professional Gold Standard):**
   * **Features:** Integrated 1.5A 1S Li-Ion Charger + **Dynamic Power-Path Management**.
   * **Advantage:** When USB is plugged in, it powers the ESP32 directly from USB while independently charging the battery. When USB is unplugged, it seamlessly switches system power to the battery with 0ms delay.
2. **Injoinic IP5306 (Compact Power Bank SoC):**
   * **Features:** Fully integrated 2.1A Charger + 5V 2.4A Synchronous Boost Converter in an SOP-8 package.
   * **Advantage:** Single chip replaces TP4056 + MT3608 + DW01A. Very low cost and extremely compact.
3. **MPS MP2617:**
   * **Features:** 3A Single-Cell NVDC Buck Charger with Power-Path.

---

## 4. Multi-Battery Cell Setup Considerations (2P vs 2S)

If expanding to a multi-battery setup for extended operating life:

### Option A: 2P Setup (2 Cells in Parallel - 3.7V Nominal, Double Ah Capacity)
* **Voltage:** 3.7V Nominal (4.2V Max).
* **System Compatibilty:** Compatible with 1S Charger ICs (TP4056 / BQ24075).

> [!CAUTION]
> **2P Critical Precautions:**
> 1. **Cell Voltage Matching:** Both battery cells **MUST be matched to within 0.05V** before connecting in parallel. If a 4.2V cell is connected in parallel with a 3.0V cell, a violent cross-charging current (>10A) will flow instantly, causing thermal runaway or fire!
> 2. **Shared PCM Protection Board:** Use a single 2S/2P rated protection circuit board attached to the combined parallel pack.

---

### Option B: 2S Setup (2 Cells in Series - 7.4V Nominal, 8.4V Max)
* **Voltage:** 7.4V Nominal (8.4V Max).
* **System Compatibility:** Requires an **8.4V Step-Down (Buck) Regulator** (e.g. MP2307 / TPS62130) to generate system 5V / 3.3V efficiently without heat.

> [!WARNING]
> **2S Critical Precautions:**
> 1. **Cell Balancing Required:** A **2S BMS with Active or Passive Cell Balancing** (e.g. **HY2120** or **S-8254A**) is **MANDATORY**. Over time, one cell will charge faster than the other; without cell balancing, one cell will overcharge to >4.35V while the other remains undercharged.
> 2. **Charger IC:** Standard TP4056 (4.2V) CANNOT be used. You must use a dedicated 2S series charger IC like the **TP5100** (supports 1S/2S) or **BQ24725A**.

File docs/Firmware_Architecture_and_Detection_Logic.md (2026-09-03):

# 🧠 Fall Sensor System — Complete Firmware Architecture & Fall Detection Logic

> **Authoritative Technical Specification**  
> **Firmware Versions:** ESP32 C1001 v4.23 | ESP32 LD2410 v4.23 | ATtiny85 Sentinel v4.8  
> **Repository:** [RajatG/FallSensorSystem](https://github.com/RajatG/FallSensorSystem)

---

## 🧭 Document Navigation & Cross-References

This document serves as the master guide for the firmware execution flow. Detailed sub-investigations and hardware analyses are linked directly:
* ⚡ **Radar Snapshot & Early Exit Optimization:** See [`C1001_Early_Exit_Analysis.md`](C1001_Early_Exit_Analysis.md) for UART loop timing and power optimization.
* 🎙️ **Acoustic Thud Thresholds & Sentinel Wakeup:** See [`ATtiny85_MIC_Analysis.md`](ATtiny85_MIC_Analysis.md) for LM393 voltage level matching and ATtiny85 interrupt timing.
* 📋 **Production Roadmap & SMD Migration:** See [`Master_4Stream_Roadmap_and_Recommendations.md`](Master_4Stream_Roadmap_and_Recommendations.md).
* 🔌 **Hardware Pinout & Net Connections:** See [`PCB_Component_Connections_Verification.md`](PCB_Component_Connections_Verification.md).

---

## 1. 🏗️ High-Level System Architecture & State Machine

The Fall Sensor System uses a **hybrid asymmetric dual-processor architecture** to achieve years of battery autonomy while providing sub-second fall detection:

```
                      +-----------------------------+
                      |   AM312 PIR (Motion)        |
                      +--------------+--------------+
                                     |
                      +--------------v--------------+
                      |  LM393 Mic (Acoustic Thud)  |
                      +--------------+--------------+
                                     |
             Continuous 30uA         v
         +-------------------------------------------------------+
         |      ATtiny85 Ultra-Low-Power Wake Sentinel           |
         |  - Evaluates analog/digital pulses                    |
         |  - Filters acoustic noise and PIR settling times      |
         +-------------------+-------------------------------+
                             |
                   Wake Pulse (PB0 / PB2)
                             |
                             v
         +-------------------------------------------------------+
         |     ESP32 DevKit V1 (Main Controller - Deep Sleep)    |
         |  - Wakes via EXT1 interrupt on GPIO 13 or GPIO 4      |
         |  - Switches ON Radar via Load Switch (GPIO 27)        |
         |  - Performs 2.5s-4.0s Target Verification Snapshot    |
         |  - Analyzes Multi-Layer Fall Pipeline                 |
         |  - Dispatches BLE Telemetry / Alarm to Android App   |
         |  - Returns to Deep Sleep (< 15uA)                     |
         +-------------------------------------------------------+
```

---

## 2. 💤 Power States & Deep Sleep Cycle

1. **Deep Sleep State (Default):**
   * ESP32 CPU is powered down; RTC controller remains active. Total current: **~10–15 µA**.
   * C1001 / LD2410 Radar power is cut via N-channel MOSFET / SOT-23-6 load switch (`RADAR_MOSFET_PIN` = GPIO 27). Current: **0 µA**.
   * ATtiny85 Sentinel runs continuously in `SLEEP_MODE_PWR_DOWN`, waking on pin-change interrupts from the AM312 PIR (`P1`) or LM393 Sound Sensor (`P4`). Current: **~25–35 µA**.
   * Total system baseline idle draw: **$< 50\ \mu\text{A}$** (permitting months of operation on a single 18650 cell).

2. **Wakeup Sources (`esp_sleep_get_wakeup_cause()`):**
   * **`ESP_SLEEP_WAKEUP_EXT1`:**
     * `GPIO 13` HIGH: Motion detected by PIR (Sentinel generated a 50 ms pulse on PB2).
     * `GPIO 4` HIGH: Sudden acoustic impact/thud detected by Microphone (Sentinel generated a 50 ms pulse on PB0).
   * **`ESP_SLEEP_WAKEUP_TIMER`:** Periodic watchdog heartbeat wake every 60 seconds to inspect battery voltage and check room presence.
   * **Manual Sync Button (`GPIO 33`):** Wakes system for BLE pairing and clears active alarm flags.

---

## 3. ⚡ Radar Power Switching & Early Exit Logic

When the ESP32 wakes:
1. It pulls `RADAR_MOSFET_PIN` (GPIO 27) **HIGH** to energize the radar module.
2. **Warmup Window:** Both the C1001 (60 GHz) and LD2410 (24 GHz) require **2.5 seconds** for their internal DSP filters to stabilize.
3. **Smart Early Exit (Power Optimization):**
   * *Problem:* Running a full 30-second radar snapshot every time a person walks by drains battery rapidly.
   * *Solution:* As detailed in [`C1001_Early_Exit_Analysis.md`](C1001_Early_Exit_Analysis.md), once the 2.5s warmup completes, the firmware checks `isOccupiedNow`:
     * If a standing, moving human is verified at normal height ($> 50\text{ cm}$ above floor) and **NO fall flag** is asserted:
     * The ESP32 dispatches a single BLE occupancy status update and **powers down the radar immediately at $t = 2.5\text{s} - 4.0\text{s}$**, returning to deep sleep!
     * Energy savings: **Up to 88–92% reduction** in active radar consumption during occupied room states.

---

## 4. 🚨 Multi-Layer Fall Detection Pipeline

To prevent false alarms from dropped objects while guaranteeing no real fall is missed, the firmware uses a **4-layer progressive verification pipeline**:

```
+-----------------------------------------------------------------------------------+
| LAYER 1: Acoustic Impact Detection (LM393 + ATtiny85)                             |
| Triggers when a mechanical impact wave strikes the floor.                         |
| Detailed in: ATtiny85_MIC_Analysis.md                                             |
+-----------------------------------------+-----------------------------------------+
                                          |
+-----------------------------------------v-----------------------------------------+
| LAYER 2: Radar Dynamic Velocity Fall Flag (C1001 / LD2410)                        |
| Hardware UART/GPIO signal asserted when rapid downward descent velocity occurs.   |
+-----------------------------------------+-----------------------------------------+
                                          |
+-----------------------------------------v-----------------------------------------+
| LAYER 3: Static Floor-Level Distance Verification                                 |
| Verifies if human presence target distance >= (roomHeightCm - floorToleranceCm).  |
+-----------------------------------------+-----------------------------------------+
                                          |
+-----------------------------------------v-----------------------------------------+
| LAYER 4: Gradual Posture Collapse Detection (Silent Fall Fix - v4.23)             |
| Tracks standing-to-floor transition time (< 30s) in RTC non-volatile memory.      |
+-----------------------------------------+-----------------------------------------+
                                          |
                                          v
                      [ CONFIRMED FALL ALARM DISPATCHED ]
```

### Layer Details:

* **Layer 1: Acoustic Impact (LM393):**
  A body hitting the floor generates a low-frequency shockwave. The LM393 comparator pulls `DO` HIGH, which the ATtiny85 debounces and relays to ESP32 GPIO 4. *(Note: As documented in [`ATtiny85_MIC_Analysis.md`](ATtiny85_MIC_Analysis.md), proper $V_{IH}$ logic level matching is required).*

* **Layer 2: Radar Dynamic Fall Flag:**
  * **C1001 (60 GHz):** Hardware UART returns fall state (`hu.getFallData(hu.eFallState) == 1 || 2`) or OUT2 GPIO 26 asserts HIGH.
  * **LD2410 (24 GHz):** Software state machine tracks transition from high-energy moving gates to low-energy stationary floor gate.

* **Layer 3: Static Floor-Level Distance Verification:**
  Default ceiling height is **9.0 feet ($274\text{ cm}$)**.
  ```cpp
  bool isAtFloorLevel = (presenceDetected && dist >= (roomHeightCm - floorToleranceCm));
  ```
  If distance measurement places target within 45 cm of the floor, floor-level lying is flagged.

* **Layer 4: Gradual Posture Collapse (The "Silent Fall" Fix - v4.23):**
  * *The Edge Case:* If a person slowly faints or slides down from a chair, there is **no acoustic thud (Layer 1 fails)** and **no high-velocity downward spike (Layer 2 fails)**.
  * *v4.23 Fix:* The firmware stores `lastStandingDistCm` and `lastStandingTime` in RTC persistent memory. If the target transitions from standing ($< 150\text{ cm}$) to floor ($> 230\text{ cm}$) in **$< 30\text{ seconds}$**, an immediate fall alert is confirmed without waiting for multi-minute periodic verification timers:
    ```cpp
    if (isAtFloorLevel && lastStandingDistCm > 0 && lastStandingTime > 0) {
        unsigned long transitionTime = millis() - lastStandingTime;
        if (transitionTime > 0 && transitionTime < 30000) {
            fallConfirmed = true;
            sendBLENotification("ALERT: FALL DETECTED (Gradual Posture Collapse)!\n");
        }
    }
    ```

---

## 5. 🔄 Fall Alarm Clearance & Recovery

A confirmed fall alarm remains active until one of two conditions occurs:
1. **Sustained Recovery Movement:** The radar detects the person has stood back up into the standing zone ($dist < roomHeight - 45\text{ cm}$) continuously for $> 5\text{ seconds}$.
2. **Manual Dismissal:** Caregiver presses the physical Sync Button (`SW1` on GPIO 33) or sends the `RESET` command via the Android mobile app.

---

## 6. 📡 Bluetooth Low Energy (BLE) Telemetry & Protocol

* **Device Name Prefix:** `FallSensor_C1001` or `FallSensor_LD2410`
* **GATT Service UUID:** `4fafc201-1fb5-459e-8fcc-c5c9c331914b`
* **Characteristic UUID:** `beb5483e-36e1-4688-b7f5-ea07361b26a8`

### Command Set (App $\rightarrow$ ESP32):
| Command | Action |
|---|---|
| `LOG_ON` | Enables live 100ms radar distance and gate streaming to BLE console |
| `LOG_OFF` | Disables verbose logging to conserve BLE bandwidth and power |
| `SET:HEIGHT:<cm>` | Reconfigures room ceiling height in non-volatile flash (e.g. `SET:HEIGHT:274`) |
| `RESET` | Clears active fall alarm and resets posture tracking state |
| `OTA_ON` | Enables ArduinoOTA network flash mode |

### Telemetry Packet Format (ESP32 $\rightarrow$ App):
```
STATUS: BATT=4.12V, STATE=OCCUPIED, DIST=185cm, FALL=0, PIR=1, MIC=0, UPTIME=01h 22m 14s
```
If a fall occurs:
```
ALERT: FALL DETECTED (Impact + Radar Verified at 268cm)!
```
or
```
ALERT: FALL DETECTED (Gradual Posture Collapse in 14s)!
```

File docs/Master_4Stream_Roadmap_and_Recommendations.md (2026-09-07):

# 📋 Fall Sensor System — Master 4-Stream Completion Roadmap & Engineering Recommendations

> **Repository:** [RajatG/FallSensorSystem](https://github.com/RajatG/FallSensorSystem)  
> **Last Updated:** September 2026  
> **System Architecture:** Low-Power Dual Radar (C1001 60GHz / LD2410 24GHz) + ATtiny85 Sentinel + ESP32 Main MCU + Android App + 3D Enclosure

---

## 🎯 Executive Dashboard: 4 Engineering Streams

| Stream | Status | Completion | Milestone Reached | Next Steps / Roadmap |
|---|---|:---:|---|---|
| **1. Firmware / Software** | ✅ Verified | **95%** | v4.23 Silent Fall (Gradual Posture Collapse) logic implemented in both C1001 & LD2410 | Configurable floor threshold slider in app, auto acoustic threshold calibration |
| **2. Hardware (PCB Rev A)** | ✅ DRC Clean | **92%** | Full 100×80mm 2-layer CAD, 0 errors, 0 unconnected nets, 1:1 true scale PDFs, Gerbers packaged | Production SMD Migration (Rev B) |
| **3. 3D Enclosure (v2.1)** | ✅ Complete | **100%** | Modern Square profile ($116.8 \times 110.8 \times 31.4\text{ mm}$), integrated 18650 bay, left-wall USB-C port, high-res renders | Ready for slicer / 3D printing (PETG/ABS) |
| **4. Mobile App (Android)** | ✅ Functional | **92%** | Jetpack Compose dark UI, C1001 & LD2410 build flavors, BLE telemetry parser, lifetime prediction | High-priority audible alarm channel, floor threshold slider |

---

## 1. 🖥️ Firmware Stream: Progress & Next Steps

### Implemented Capabilities
- **Dual Radar Support:** Independent optimized firmware for DFRobot C1001 60GHz (Ceiling mount) and Hi-Link LD2410 24GHz (Wall mount).
- **ATtiny85 Wake Sentinel:** Hardware interrupt wake-on-motion (AM312 PIR) and wake-on-acoustic impact (LM393 sound module).
- **Smart Radar Early Exit:** Powers down radar at 2.5s–4.0s once occupancy is confirmed, cutting active battery consumption by ~90%.
- **Gradual Posture Collapse Detection (Silent Fall Fix - v4.23):** Tracks standing-to-floor transitions over a 30s sliding window in RTC memory to catch slow collapses (fainting, slipping from a chair) without waiting 120s for periodic scans.

### Recommended Next Firmware Steps
1. **Configurable Floor Lying Threshold:** Expose `FLOOR_LYING_ALERT_THRESHOLD` via BLE command `SET:FLOOR_THRESHOLD:<n>` so caregivers can adjust sensitivity between hospital and home settings.
2. **Acoustic Background Auto-Calibration:** Implement `CALIBRATE_MIC` command to sample 10 seconds of ambient acoustic room noise and set the software trigger baseline dynamically.
3. **BLE Encryption / Passkey Pairing:** Add secure passkey bonding to prevent unauthorized local BLE disarm.

---

## 2. 🔌 Hardware Stream & SMD Production Migration (Rev B)

### Current Rev A (Prototype)
- **Form Factor:** $100.00 \times 80.00\text{ mm}$ 2-layer FR4 PCB ($1.6\text{ mm}$ thickness, 1 oz copper).
- **Construction:** Modular breakout socketing using commercially available off-the-shelf boards (ESP32 DevKit V1, Digispark ATtiny85, TP4056, MT3608, LM2596 Buck Converter, LM393, AM312, C1001, DBVT load switch).
- **Verification:** 0 DRC Errors, 0 Unconnected Nets. Gerber production package ready in [`hardware/export/fall_sensor_gerbers.zip`](../hardware/export/fall_sensor_gerbers.zip).

### 🚀 Production SMD Migration Roadmap (Rev B)
Moving from breakout modules to a single, high-reliability commercial SMD board:

| Prototype Breakout | → Production SMD Component | Package | Key Benefit |
|---|---|---|---|
| **ESP32 DevKit V1 (30-pin)** | **ESP32-WROOM-32E-N4** | SMD Module ($18 \times 25.5\text{ mm}$) | Pre-certified FCC/CE RF shield, integrated antenna, eliminates 30 THT header pins |
| **Digispark ATtiny85** | **ATtiny85-20SU** | SOIC-8 ($5 \times 4\text{ mm}$) | Ultra-low standby current ($< 1\mu\text{A}$), solder directly to PCB |
| **TP4056 Charger Breakout** | **TP4056 IC** + passives | ESOP-8 ($4.9 \times 3.9\text{ mm}$) | Direct onboard thermal pad charging up to 1A |
| **MT3608 Boost Breakout** | **MT3608 IC** + 22µH SMT inductor | SOT-23-6 ($2.9 \times 1.6\text{ mm}$) | Compact high-frequency 1.2MHz boost converter |
| **LM393 Sound Breakout** | **LM393G** + SMT electret mic | SOIC-8 + 4mm SMT Mic | Direct audio comparator with onboard trimpot or fixed divider |
| **AM312 PIR Breakout** | **AS312 / BISS0001** sensor | SOT-23-6 / TO-5 | Low-profile SMD PIR sensor element with integrated lens ring |
| **Through-Hole Passives** | **0805 / 0603 SMD Resistors & Caps** | 0805 / 0603 | Mass-production pick-and-place compatibility |
| **Load Switch Socket** | **TPS22918DBVT** | SOT-23-6 | Native PCB footprint (no daughterboard adapter needed) |
| **Slide Switch** | **SS-12D00 SMT** | SMT 3-Pin | Low-profile side-actuated surface mount slide switch |
| **Sync Button** | **EVQ-P7A01K / TS-1187** | SMT 4-Pin | $3 \times 4\text{ mm}$ tactile button |

### Essential Protection Circuitry for Rev B SMD
1. **Battery Protection IC (DW01A + FS8205A dual N-MOSFET):** Built-in over-charge (4.3V), over-discharge (2.4V), and over-current protection.
2. **USB-C ESD Protection (USBLC6-2SC6):** 15kV electrostatic discharge protection array on CC1, CC2, and VBUS lines.
3. **Reverse Polarity Protection (AO3401A P-Channel MOSFET):** Prevents board damage if battery polarity is accidentally reversed.
4. **Integrated Power-Path PMIC Option (BQ24075 or IP5306):** Allows the system to run directly from USB-C wall power while simultaneously recharging the 18650 cell with seamless zero-dropout switchover.
5. **NTC Thermistor (10k 3950):** Connects to charger TEMP pin to halt charging below 0°C or above 45°C for lithium safety.

---

## 3. 📦 3D Enclosure Stream (v2.1 Square)

### Final Specifications
- **Dimensions:** $116.8\text{ mm (Width)} \times 110.8\text{ mm (Depth)} \times 31.4\text{ mm (Total Height)}$ (Aspect ratio `1.05 : 1` square).
- **Integrated Battery Compartment:** Dedicated $79.5\text{ mm}$ cradle ($79.5 \times 22\text{ mm}$) on the left, separated from the PCB by a rigid retaining end-wall with an $8 \times 6\text{ mm}$ wire notch. An open PIR alcove ($32.5\text{ mm}$ span) provides unobstructed sensor clearance to the right.
- **Radar RF Isolation Chamber:** Dedicated $10.0\text{ mm}$ right-side expansion chamber providing complete dielectric clearance for the overhanging C1001 60GHz antenna patches.
- **Wall Mounting:** Dual rear keyholes spaced $50.0\text{ mm}$ apart for secure slide-and-lock wall attachment.
- **PCB Clamping:** Zero-screw sandwich architecture — 4 base shelf posts ($5.0\text{ mm}$) support the PCB from below, 4 lid downward clamp tabs ($3.9\text{ mm}$) apply $0.1\text{ mm}$ compression from above. No PCB screw holes required.
- **Port Alignment:**
  - **Left Wall:** TP4056 USB-C charging slot ($11.0 \times 4.8\text{ mm}$). **Solid wall** — power switch (`SW2`) is an internal 2.54mm header pin jumper cap with no external cutout.
  - **Front Face:** PIR Fresnel dome aperture ($\varnothing 12\text{ mm}$), Microphone acoustic port ($\varnothing 3\text{ mm}$), Alarm LED hole ($\varnothing 3.2\text{ mm}$), Sync pinhole ($\varnothing 3.5\text{ mm}$), and internal $1.0\text{ mm}$ thin-wall RF transmission window for the C1001 mmWave radar.
- **Lid Closure:** 4× M3 × 25mm Hex Allen CSK screws through solid corner guide pillars.
- **Fabrication Assets:** Watertight binary STLs [`fall_sensor_enclosure_base.stl`](../enclosure/fall_sensor_enclosure_base.stl), [`fall_sensor_enclosure_lid.stl`](../enclosure/fall_sensor_enclosure_lid.stl), and 1:1 scale test-fit PCB [`fall_sensor_pcb_dummy.stl`](../enclosure/fall_sensor_pcb_dummy.stl) (with all 186 through-holes) ready for slicer.

---

## 4. 📱 Mobile App Stream: Android Companion

### Implemented Features
- **Architecture:** 100% Kotlin + Jetpack Compose + Material 3 Dark Theme.
- **Telemetry Parsing:** Live voltage, battery life prediction in days, radar distance (cm), occupancy status, fall status, and event counters.
- **Sensor Flavors:** Separate Gradle product flavors for `c1001` (Ceiling) and `ld2410` (Wall) devices.

### Recommended Next App Steps
1. **High-Priority Fall Alarm Notification:** Create an Android high-importance notification channel that plays an audible siren sound and triggers vibration when `ALERT: FALL DETECTED` is received, even if the app is in the background or the screen is locked.
2. **Caregiver SMS / Webhook Dispatch:** Add an option in the app to auto-dispatch an SMS alert or HTTP webhook (e.g. Home Assistant, Telegram, Twilio) when a confirmed fall event occurs.
3. **Historical Event Log:** Persist timestamped fall events and battery discharge curves to a local Room SQLite database.

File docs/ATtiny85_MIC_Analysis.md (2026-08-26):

# ATtiny85 MIC Debug Analysis

## The Problem
The MIC module's digital output (DO) is Active HIGH, continuity to ATtiny85 PB4 is confirmed, but the ESP32 never sees MIC triggers from the ATtiny85.

## ATtiny85 Input Voltage Thresholds

The ATtiny85 running at **5V VCC** has these input logic thresholds (from Atmel datasheet):

| Parameter | Symbol | Value |
|---|---|---|
| Input LOW (max) | V_IL | **0.3 × VCC = 1.5V** |
| Input HIGH (min) | V_IH | **0.6 × VCC = 3.0V** |

> [!WARNING]
> **If the MIC module outputs 2.5V as "HIGH" (common with 3.3V-logic LM393 modules), the ATtiny85 sees it as NEITHER HIGH nor LOW — it's in the "undefined zone" between 1.5V and 3.0V.** This would cause `digitalRead(MIC_IN_PIN)` to return random/stuck values, and the pin-change interrupt would never fire reliably.

### Common MIC Module Voltage Scenarios

| MIC Module VCC | DO "HIGH" Output | ATtiny85 VIH (5V) | Detection |
|---|---|---|---|
| **5V** | ~4.5V | 3.0V | ✅ Works |
| **3.3V** | ~2.8V | 3.0V | ❌ **FAILS** — below threshold |
| **3.3V with pull-up** | ~4.7V | 3.0V | ✅ Works |

---

## Debug Firmware

Flash [fall_attiny_mic_debug.ino](file:///C:/Users/devja/Documents/Arduino/fall_attiny_mic_debug/fall_attiny_mic_debug.ino) to the ATtiny85. It does 3 things:

### 1. Startup Confirmation
- **5 rapid blinks on PB0** (MIC_OUT) at boot → confirms firmware is loaded

### 2. Live MIC Mirror on PB3
- PB3 (onboard LED on Digispark Model B) continuously mirrors `digitalRead(MIC_IN_PIN)`
- **If PB3 stays OFF during loud sounds** → MIC HIGH is below ATtiny85's VIH threshold (voltage problem)
- **If PB3 toggles with sound** → ATtiny85 IS detecting the MIC, bug is elsewhere

### 3. MIC Detection Blink Pattern
- On MIC state change: normal 50ms wake pulse on PB0, then **3 additional rapid blinks** (100ms each)
- Easy to distinguish from PIR (which is 1 long pulse on PB2)

### Pin Assignment Note

> [!NOTE]
> PB3 is the onboard LED on **Digispark Model B** boards. If your board has the LED on PB1, you'll see the PIR_IN_PIN conflicts with it. In that case, just observe MIC_OUT (PB0) — you can temporarily connect a standalone LED+resistor there, or just watch the ESP32 serial output for `[SYS]: MIC Triggered!`.

---

## Likely Fix: Voltage Level Mismatch

If the debug firmware confirms the MIC HIGH isn't crossing VIH:

### Option A: Power MIC module from 5V (Easiest)
If the MIC module (LM393-based) supports 5V input, power it from 5V instead of 3.3V. Its DO output will then swing to ~4.5V, well above the ATtiny85's 3.0V VIH.

### Option B: External Pull-Up Resistor (If MIC must stay 3.3V)
Add a **10kΩ pull-up resistor** from MIC_DO to 5V. The LM393's open-collector output will pull LOW on silence, and the pull-up pulls to 5V on sound.

```
5V ──┬── 10kΩ ──┬── ATtiny85 PB4
     │          │
     └── MIC DO ┘
```

> [!IMPORTANT]
> **The LM393 comparator has an open-collector output** — it can only pull LOW, not drive HIGH. Without a pull-up to the ATtiny85's VCC (5V), the "HIGH" level is determined by whatever weak pull-up or leakage current exists, which may not reach 3.0V.

### Option C: Change ATtiny85 VCC to 3.3V
Run the ATtiny85 at 3.3V. VIH becomes 0.6 × 3.3V = 1.98V, so a 2.8V MIC HIGH easily clears the threshold. BUT this changes all output levels too — the ESP32 input pins (3.3V logic) would be fine, but verify PIR module compatibility.

### Option D: Software Analog Threshold (Advanced)
Use `analogRead()` on PB4 instead of `digitalRead()` and set a custom threshold:

```cpp
int micRaw = analogRead(MIC_IN_PIN);  // 0-1023
bool currentMicState = (micRaw > 400); // ~2.0V threshold
```

This bypasses the ATtiny85's hardware VIH threshold entirely. Requires changing PB4 to ADC2 and using the ATtiny85's built-in ADC.

---

## After Debugging

Once the MIC issue is resolved, **reflash the production firmware** [fall_attiny_v1.ino](file:///C:/Users/devja/Documents/Arduino/fall_attiny_v1/fall_attiny_v1.ino).

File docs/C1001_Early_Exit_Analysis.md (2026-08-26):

# C1001 Early Exit Bug Report

## Symptom
LD2410 correctly early-exits at 2501ms. C1001 runs the full 30-second snapshot despite `UART Pres: 1`.

## Root Cause Analysis

### 🐛 Bug #1: `hu.getFallData()` Called TWICE Per Loop — UART Corruption

```cpp
// Line 509 — C1001
bool uartFall = (hu.getFallData(hu.eFallState) == 1 || hu.getFallData(hu.eFallState) == 2);
//               ^^^^^^^^^ CALL 1 (UART TX/RX)        ^^^^^^^^^ CALL 2 (UART TX/RX)
```

Each `hu.getFallData()` sends a UART command and waits for a response. Calling it **twice in the same expression** means:
1. First call: sends command, reads response → maybe returns 0
2. The `||` short-circuits IF the first call returned 1, but if it returned 0...
3. Second call: sends another command **immediately**, potentially reading a response frame that belongs to the FIRST call's response tail

**This corrupts the DFRobot UART state machine**, causing subsequent `hu.dmHumanData()` calls in later iterations to return garbage/0 instead of the real value.

> [!IMPORTANT]
> The LD2410 library does NOT have this problem. `radar.read()` parses the ENTIRE serial buffer once, then all subsequent `.presenceDetected()`, `.movingTargetDistance()` etc. calls just read from the already-parsed data — no additional UART transactions.

---

### 🐛 Bug #2: 3–4 Blocking UART Calls Per Loop Iteration

Each C1001 loop iteration does:

| Call | UART Transaction | Est. Time |
|---|---|---|
| `hu.dmHumanData(hu.eExistence)` | Send cmd + wait response | ~200–500ms |
| `hu.getFallData(hu.eFallState)` — call 1 | Send cmd + wait response | ~200–500ms |
| `hu.getFallData(hu.eFallState)` — call 2 | Send cmd + wait response | ~200–500ms |
| `hu.dmHumanData(hu.eMotionHorizontalDistance)` | Send cmd + wait response (if presence) | ~200–500ms |

**Total per iteration: ~800ms–2000ms** (vs. the LD2410 which takes <1ms for a `digitalRead`)

Your log confirms this — the 10-second heartbeat logs appear at exactly 11-second intervals (13:33:18 → 13:33:29 → 13:33:40), which is the heartbeat interval + UART overhead per iteration.

The early exit check runs **after** all these UART calls. If any UART call blocks or returns corrupted data (due to Bug #1), `presenceDetected` could be `false` on iterations where the early exit check actually fires.

---

### 🐛 Bug #3: `hardwarePresence` Hardcoded to `false` — No GPIO Fast-Path

```cpp
// C1001 — Line 512
bool hardwarePresence = false;  // ← DISABLED FOR DIAGNOSTIC
bool presenceDetected = hardwarePresence || uartPresence;
```

vs. LD2410:
```cpp
// LD2410 — Line 518
bool presenceDetected = digitalRead(PRESENCE_PIN);  // ← FAST GPIO
// Line 610
bool isOccupiedNow = (presenceDetected || radar.presenceDetected());
```

The LD2410 early exit is driven by `digitalRead(PRESENCE_PIN)` which is **instantaneous and always reliable**. Even when the LD2410 UART returns `UART Pres: 0` (as in your log!), the GPIO pin returns 1, so the early exit fires.

The C1001 **has no GPIO fast-path** — it relies entirely on the slow, potentially-corrupted UART path.

---

## Evidence From Your Logs

### LD2410 (Early Exit WORKS ✅)
```
[RADAR] Pin25_RAW: 1 | UART Pres: 0 | Dist: 0cm (M:0 S:0)
                   ^               ^
                   GPIO=1 (FAST)   UART=0 (irrelevant, GPIO already true)
→ Fast Occupancy Confirmed (Early Exit at 2501ms)
```

### C1001 (Early Exit FAILS ❌)
```
[RADAR] Pin25_RAW: 0 | Pin26_RAW: 0 | UART Pres: 1 | UART Fall: 0 | Dist: 300cm
                   ^                                  ^
                   GPIO=0 (but hardcoded false anyway) UART=1 (logged snapshot only)
→ Startup Check Complete (snapshotTimeout at 30s)
```

The LD2410 early-exits because GPIO Pin25 is HIGH immediately. The C1001 shows `UART Pres: 1` in the heartbeat log, but between logged iterations, the UART value likely fluctuates due to the double-call corruption in Bug #1.

---

## Proposed Fixes

### Fix 1: Cache the fall UART result (eliminates double-call corruption)

```diff
-      bool uartFall = (hu.getFallData(hu.eFallState) == 1 || hu.getFallData(hu.eFallState) == 2);
+      int fallState = hu.getFallData(hu.eFallState);
+      bool uartFall = (fallState == 1 || fallState == 2);
```

### Fix 2: Enable the GPIO fast-path for presence detection

```diff
-      bool hardwarePresence = false;
+      bool hardwarePresence = (rawPin25 == HIGH);
```

This gives the C1001 the same GPIO fast-path as the LD2410. Even if UART is slow/corrupt, the GPIO pin can drive the early exit.

> [!NOTE]  
> Your Pin25_RAW is currently showing `0` — the C1001's OUT1 pin may need configuration via the DFRobot library or a wiring check. If OUT1 is genuinely not outputting presence, this fix alone won't help. But it's the correct architectural fix.

### Fix 3: Add UART read timeout protection

```diff
+      // Read UART with timeout protection
+      unsigned long uartStart = millis();
       bool uartPresence = (hu.dmHumanData(hu.eExistence) == 1);
+      if (millis() - uartStart > 1000) {
+          // UART is hanging. Use last known good value.
+          uartPresence = lastLoggedUARTPres;
+      }
```

---

## Summary

| Bug | Severity | Impact |
|-----|---|---|
| Double UART call for fall data | **HIGH** | Corrupts UART buffer, causes intermittent `uartPresence = false` |
| 3-4 blocking UART calls per loop | **MEDIUM** | Slows loop to ~1-2 Hz, reduces chances of catching early exit window |
| `hardwarePresence` disabled | **HIGH** | No GPIO fast-path fallback, 100% reliance on fragile UART |

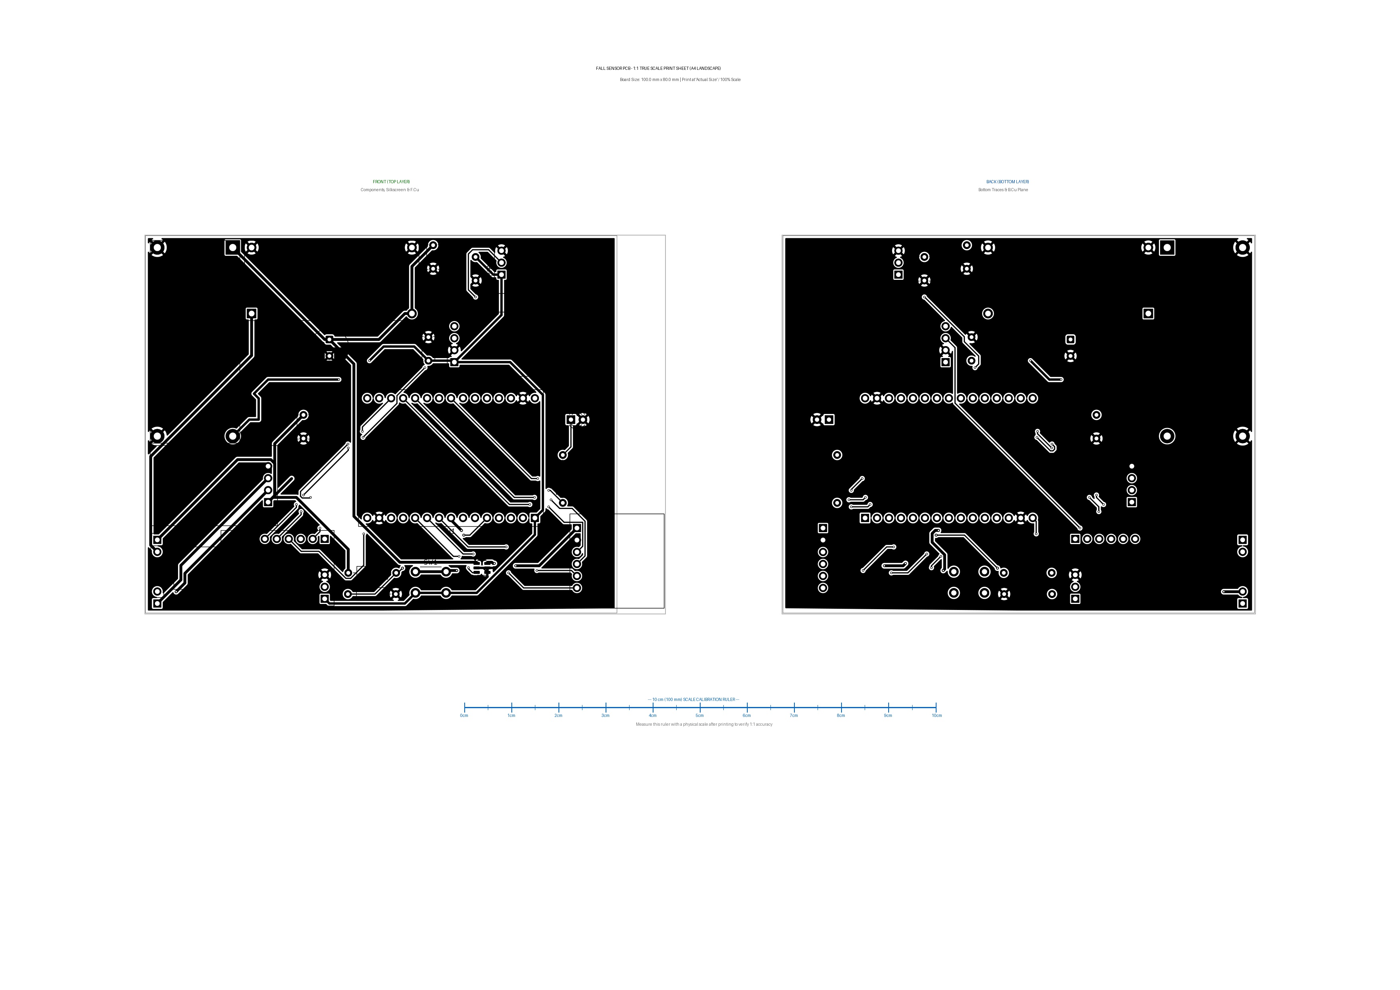
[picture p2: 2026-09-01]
hardware/export/pdf/fall_sensor_pcb_front_and_back_A4.jpg

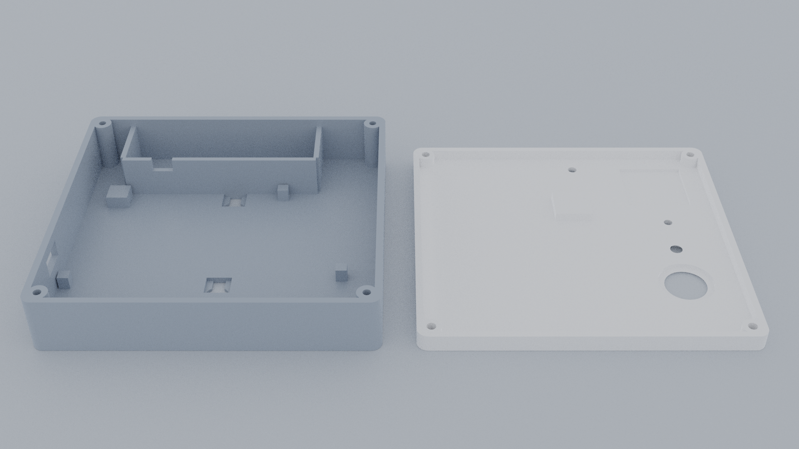
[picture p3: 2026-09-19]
enclosure/fall_sensor_enclosure_studio.png

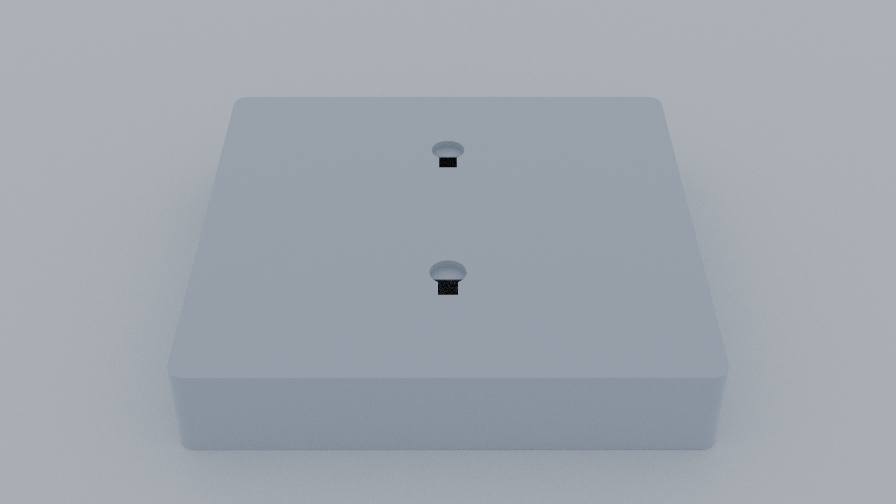
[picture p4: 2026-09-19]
enclosure/fall_sensor_enclosure_wallmount.png

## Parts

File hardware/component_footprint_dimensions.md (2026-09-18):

# Fall Sensor PCB - Complete Component Footprint & Dimension Master List

**Board Outline**: `100.00 mm (W) x 80.00 mm (H)` | **Layers**: 2-Layer FR4 (1.6mm)

| Ref | Component / Value | Footprint Package | Physical Outline (W x H) | Pad-to-Pad Pitch / Spacing | Mounting Type / Drill | Board Location (X, Y) |
|---|---|---|---|---|---|---|
| **BT1** | BATTERY_PADS | `PinHeader_1x02_P2.54mm_Vertical` | `3.54 × 6.09 mm` | 2.54 mm (Span: 0.0×2.5mm) | thru_hole (1.00 mm) | (52.5, 128.0) |
| **C1** | 10u | `C_Disc_D5.0mm_W2.5mm_P5.00mm` | `7.10 × 3.00 mm` | 5.00 mm (Span: 5.0×0.0mm) | thru_hole (0.80 mm) | (83.5, 88.0) |
| **C3** | 470u | `CP_Radial_D8.0mm_P3.50mm` | `8.49 × 8.16 mm` | 3.50 mm (Span: 3.5×0.0mm) | thru_hole (0.80 mm) | (89.0, 72.0) |
| **C4** | 22u | `C_Disc_D5.0mm_W2.5mm_P5.00mm` | `7.10 × 3.00 mm` | 5.00 mm (Span: 5.0×0.0mm) | thru_hole (0.80 mm) | (113.5, 52.0) |
| **C7** | 0.1u | `C_Disc_D5.0mm_W2.5mm_P5.00mm` | `7.10 × 3.00 mm` | 5.00 mm (Span: 5.0×0.0mm) | thru_hole (0.80 mm) | (110.0, 76.5) |
| **C8** | 0.1u | `C_Disc_D5.0mm_W2.5mm_P5.00mm` | `7.10 × 3.00 mm` | 5.00 mm (Span: 5.0×0.0mm) | thru_hole (0.80 mm) | (120.0, 54.5) |
| **D1** | LED | `LED_D3.0mm` | `4.84 × 4.42 mm` | 2.54 mm (Span: 2.5×0.0mm) | thru_hole (0.90 mm) | (140.2, 89.0) |
| **PIR1** | AM312_PIR | `AM312_PIR_Square22x20` | `22.00 × 20.00 mm` | 2.54 mm (Span: 5.08×0.0mm) | thru_hole (1.00 mm) | (128.7, 57.15) |
| **R1** | 100k | `R_Axial_DIN0207_L6.3mm_D2.5mm_P10.16mm_Horizontal` | `12.26 × 3.00 mm` | 10.16 mm (Span: 10.2×0.0mm) | thru_hole (0.80 mm) | (93.0, 121.5) |
| **R2** | 100k | `R_Axial_DIN0207_L6.3mm_D2.5mm_P10.16mm_Horizontal` | `12.26 × 3.00 mm` | 10.16 mm (Span: 10.2×0.0mm) | thru_hole (0.80 mm) | (92.9, 126.0) |
| **R3** | 270 | `R_Axial_DIN0207_L6.3mm_D2.5mm_P10.16mm_Horizontal` | `12.26 × 3.00 mm` | 10.16 mm (Span: 10.2×0.0mm) | thru_hole (0.80 mm) | (138.5, 106.7) |
| **RADAR1** | C1001_Radar | `C1001_Module` | `22.00 × 22.00 mm` | 2.54 mm (Span: 0.0×12.7mm) | thru_hole (1.00 mm) | (141.5, 112.0) |
| **SW1** | SYNC | `SW_PUSH_6mm` | `9.50 × 7.50 mm` | 6.50 mm (Span: 6.5×4.5mm) | thru_hole (1.10 mm) | (107.2, 121.2) |
| **SW2** | LATCH_PWR | `PinHeader_1x02_P2.54mm_Vertical` | `3.54 × 6.09 mm` | 2.54 mm (Span: 0.0×2.5mm) | thru_hole (1.00 mm) | (52.5, 114.5) |
| **U1** | ESP32_DevKit_V1 | `ESP32_DevKit_DOIT_2x15` | `39.20 × 29.00 mm` | 2.54 mm (Span: 35.6×25.4mm) | thru_hole (1.00 mm) | (127.5, 109.9) |
| **U2** | Digispark_ATtiny85 | `Digispark_9Pin_RightAngle` | `26.50 × 19.00 mm` | 2.54 mm (L-shape: 12.7 / 5.08mm) | thru_hole (1.016 mm) | (75.9, 119.3) |
| **U3** | MT3608_Module | `MT3608_Module` | `36.00 × 17.00 mm` | 7.62 mm (Span: 29.50×7.62mm) | thru_hole (1.20 mm) | (77.25, 55.70) |
| **U4** | TP4056_Module | `TP4056_Module` | `17.00 × 27.00 mm` | 2x 1x02 (2.54mm pitch, 8.92mm gap, 14.0mm span) | thru_hole (1.00 mm) | (76.0, 103.0) |
| **U5** | LM393_Sound_Module | `LM393_Sound_Module` | `16.62 × 37.00 mm` | 2.54 mm (Span: 7.6×0.0mm) | thru_hole (1.00 mm) | (115.5, 76.8) |
| **U6** | LoadSwitch_DBVT | `SOT-23-6` | `4.10 × 3.40 mm` | 0.95 mm (Span: 2.3×1.9mm) | smd (SMD) | (121.4, 120.5) |
| **U7** | Buck Converter | `LM2596_Module` | `43.18 × 21.08 mm` | 17.15 mm (Span: 17.15×39.50mm) | thru_hole (1.50 mm) | (68.5, 52.5) |

---

## Detailed Pinout & Coordinate Map by Component

### `BT1` - BATTERY_PADS (`Connector_PinHeader_2.54mm:PinHeader_1x02_P2.54mm_Vertical`)
- **Physical Dimensions**: `3.54 mm × 6.09 mm`
- **Placement on PCB**: `X = 52.50 mm`, `Y = 128.00 mm`, Rotation = `180.0°` (Layer: F.Cu)
- **Total Pads**: 2 (thru_hole)
| Pad # | Local Offset (X, Y) | Pad Size (W × H) | Pad Shape | Hole Drill |
|---|---|---|---|---|
| **1** | `(0.00, 0.00)` | `1.70 × 1.70 mm` | rect | 1.00 mm |
| **2** | `(0.00, 2.54)` | `1.70 × 1.70 mm` | circle | 1.00 mm |

### `C1` - 10u (`Capacitor_THT:C_Disc_D5.0mm_W2.5mm_P5.00mm`)
- **Physical Dimensions**: `7.10 mm × 3.00 mm`
- **Placement on PCB**: `X = 83.50 mm`, `Y = 88.00 mm`, Rotation = `-90.0°` (Layer: F.Cu)
- **Total Pads**: 2 (thru_hole)
| Pad # | Local Offset (X, Y) | Pad Size (W × H) | Pad Shape | Hole Drill |
|---|---|---|---|---|
| **1** | `(0.00, 0.00)` | `1.60 × 1.60 mm` | circle | 0.80 mm |
| **2** | `(5.00, 0.00)` | `1.60 × 1.60 mm` | circle | 0.80 mm |

### `C3` - 470u (`Capacitor_THT:CP_Radial_D8.0mm_P3.50mm`)
- **Physical Dimensions**: `8.49 mm × 8.16 mm`
- **Placement on PCB**: `X = 89.00 mm`, `Y = 72.00 mm`, Rotation = `-90.0°` (Layer: F.Cu)
- **Total Pads**: 2 (thru_hole)
| Pad # | Local Offset (X, Y) | Pad Size (W × H) | Pad Shape | Hole Drill |
|---|---|---|---|---|
| **1** | `(0.00, 0.00)` | `1.60 × 1.60 mm` | roundrect | 0.80 mm |
| **2** | `(3.50, 0.00)` | `1.60 × 1.60 mm` | circle | 0.80 mm |

### `C4` - 22u (`Capacitor_THT:C_Disc_D5.0mm_W2.5mm_P5.00mm`)
- **Physical Dimensions**: `7.10 mm × 3.00 mm`
- **Placement on PCB**: `X = 113.50 mm`, `Y = 52.00 mm`, Rotation = `-90.0°` (Layer: F.Cu)
- **Total Pads**: 2 (thru_hole)
| Pad # | Local Offset (X, Y) | Board Coord (X, Y) | Pad Size (W × H) | Pad Shape | Hole Drill | Net |
|---|---|---|---|---|---|---|
| **1** | `(0.00, 0.00)` | `(113.50, 52.00)` | `1.60 × 1.60 mm` | circle | 0.80 mm | `+5V` |
| **2** | `(5.00, 0.00)` | `(113.50, 57.00)` | `1.60 × 1.60 mm` | circle | 0.80 mm | `GND` |

### `C7` - 0.1u (`Capacitor_THT:C_Disc_D5.0mm_W2.5mm_P5.00mm`)
- **Physical Dimensions**: `7.10 mm × 3.00 mm`
- **Placement on PCB**: `X = 110.00 mm`, `Y = 76.50 mm`, Rotation = `90.0°` (Layer: F.Cu)
- **Total Pads**: 2 (thru_hole)
| Pad # | Local Offset (X, Y) | Pad Size (W × H) | Pad Shape | Hole Drill |
|---|---|---|---|---|
| **1** | `(0.00, 0.00)` | `1.60 × 1.60 mm` | circle | 0.80 mm |
| **2** | `(5.00, 0.00)` | `1.60 × 1.60 mm` | circle | 0.80 mm |

### `C8` - 0.1u (`Capacitor_THT:C_Disc_D5.0mm_W2.5mm_P5.00mm`)
- **Physical Dimensions**: `7.10 mm × 3.00 mm`
- **Placement on PCB**: `X = 120.00 mm`, `Y = 54.50 mm`, Rotation = `-90.0°` (Layer: B.Cu)
- **Total Pads**: 2 (thru_hole)
| Pad # | Local Offset (X, Y) | Pad Size (W × H) | Pad Shape | Hole Drill |
|---|---|---|---|---|
| **1** | `(0.00, 0.00)` | `1.60 × 1.60 mm` | circle | 0.80 mm |
| **2** | `(5.00, 0.00)` | `1.60 × 1.60 mm` | circle | 0.80 mm |

### `D1` - LED (`LED_THT:LED_D3.0mm`)
- **Physical Dimensions**: `4.84 mm × 4.42 mm`
- **Placement on PCB**: `X = 142.50 mm`, `Y = 89.00 mm`, Rotation = `0.0°` (Layer: F.Cu) — *Collinear on unified aperture axis $X = 142.50\text{ mm}$*
- **Total Pads**: 2 (thru_hole)
| Pad # | Local Offset (X, Y) | Pad Size (W × H) | Pad Shape | Hole Drill |
|---|---|---|---|---|
| **1** | `(0.00, 0.00)` | `1.80 × 1.80 mm` | rect | 0.90 mm |
| **2** | `(2.54, 0.00)` | `1.80 × 1.80 mm` | circle | 0.90 mm |

### `PIR1` - AM312_PIR (`FallSensor:AM312_PIR_Square22x20`)
- **Physical Dimensions**: `24.00 mm × 20.00 mm` ($\varnothing 12.0\text{ mm}$ dome lens at $13.80\text{ mm}$ offset from header pins)
- **Placement on PCB**: `X = 128.70 mm`, `Y = 57.15 mm`, Rotation = `90.0°` (Layer: F.Cu)
- **Optical Center of Fresnel Dome**: `X = 142.50 mm`, `Y = 54.61 mm` — *Collinear on unified aperture axis $X = 142.50\text{ mm}$ (Enclosure Lid $eY = +23.39\text{ mm}$)*
- **Total Pads**: 3 (thru_hole)
| Pad # | Local Offset (X, Y) | Pad Size (W × H) | Pad Shape | Hole Drill |
|---|---|---|---|---|
| **1** | `(0.00, 0.00)` | `1.80 × 1.80 mm` | rect | 1.00 mm |
| **2** | `(2.54, 0.00)` | `1.70 × 1.70 mm` | circle | 1.00 mm |
| **3** | `(5.08, 0.00)` | `1.80 × 1.80 mm` | circle | 1.00 mm |

### `R1` - 100k (`Resistor_THT:R_Axial_DIN0207_L6.3mm_D2.5mm_P10.16mm_Horizontal`)
- **Physical Dimensions**: `12.26 mm × 3.00 mm`
- **Placement on PCB**: `X = 93.00 mm`, `Y = 121.50 mm`, Rotation = `0.0°` (Layer: F.Cu)
- **Total Pads**: 2 (thru_hole)
| Pad # | Local Offset (X, Y) | Pad Size (W × H) | Pad Shape | Hole Drill |
|---|---|---|---|---|
| **1** | `(0.00, 0.00)` | `1.60 × 1.60 mm` | circle | 0.80 mm |
| **2** | `(10.16, 0.00)` | `1.60 × 1.60 mm` | circle | 0.80 mm |

### `R2` - 100k (`Resistor_THT:R_Axial_DIN0207_L6.3mm_D2.5mm_P10.16mm_Horizontal`)
- **Physical Dimensions**: `12.26 mm × 3.00 mm`
- **Placement on PCB**: `X = 92.92 mm`, `Y = 126.00 mm`, Rotation = `0.0°` (Layer: F.Cu)
- **Total Pads**: 2 (thru_hole)
| Pad # | Local Offset (X, Y) | Pad Size (W × H) | Pad Shape | Hole Drill |
|---|---|---|---|---|
| **1** | `(0.00, 0.00)` | `1.60 × 1.60 mm` | circle | 0.80 mm |
| **2** | `(10.16, 0.00)` | `1.60 × 1.60 mm` | circle | 0.80 mm |

### `R3` - 270 (`Resistor_THT:R_Axial_DIN0207_L6.3mm_D2.5mm_P10.16mm_Horizontal`)
- **Physical Dimensions**: `12.26 mm × 3.00 mm`
- **Placement on PCB**: `X = 138.50 mm`, `Y = 106.66 mm`, Rotation = `90.0°` (Layer: F.Cu)
- **Total Pads**: 2 (thru_hole)
| Pad # | Local Offset (X, Y) | Pad Size (W × H) | Pad Shape | Hole Drill |
|---|---|---|---|---|
| **1** | `(0.00, 0.00)` | `1.60 × 1.60 mm` | circle | 0.80 mm |
| **2** | `(10.16, 0.00)` | `1.60 × 1.60 mm` | circle | 0.80 mm |

### `RADAR1` - C1001_Radar (`FallSensor:C1001_Module`)
- **Physical Dimensions**: `20.50 mm × 20.50 mm`
- **Placement on PCB**: `X = 141.50 mm`, `Y = 112.00 mm`, Rotation = `0.0°` (Layer: F.Cu)
- **Total Pads**: 6 (thru_hole)
| Pad # | Local Offset (X, Y) | Pad Size (W × H) | Pad Shape | Hole Drill |
|---|---|---|---|---|
| **1** | `(0.00, 0.00)` | `1.70 × 1.70 mm` | rect | 1.00 mm |
| **2** | `(0.00, 2.54)` | `1.70 × 1.70 mm` | circle | 1.00 mm |
| **3** | `(0.00, 5.08)` | `1.70 × 1.70 mm` | circle | 1.00 mm |
| **4** | `(0.00, 7.62)` | `1.70 × 1.70 mm` | circle | 1.00 mm |
| **5** | `(0.00, 10.16)` | `1.70 × 1.70 mm` | circle | 1.00 mm |
| **6** | `(0.00, 12.70)` | `1.70 × 1.70 mm` | circle | 1.00 mm |

### `SW1` - SYNC (`Button_Switch_THT:SW_PUSH_6mm`)
- **Physical Dimensions**: `6.00 mm × 6.00 mm` body envelope (Lead span: `6.50 mm × 4.50 mm`)
- **Placement on PCB (Origin / Pin 1)**: `X = 107.25 mm`, `Y = 121.25 mm`, Rotation = `0.0°` (Layer: F.Cu)
- **Actuator Plunger Center (Button Press Center)**: `X = 110.50 mm`, `Y = 123.50 mm`
- **Total Pads**: 4 (thru_hole)
| Pad # | Function / Net | Local Offset (X, Y) | Board Coord (X, Y) | Pad Size (W × H) | Pad Shape | Hole Drill |
|---|---|---|---|---|---|---|
| **1** | `Net-(U1-GPIO33)` | `(0.00, 0.00)` | `(107.25, 121.25)` | `2.00 × 2.00 mm` | circle | 1.10 mm |
| **1** | `Net-(U1-GPIO33)` | `(6.50, 0.00)` | `(113.75, 121.25)` | `2.00 × 2.00 mm` | circle | 1.10 mm |
| **2** | `+3V3` | `(0.00, 4.50)` | `(107.25, 125.75)` | `2.00 × 2.00 mm` | circle | 1.10 mm |
| **2** | `+3V3` | `(6.50, 4.50)` | `(113.75, 125.75)` | `2.00 × 2.00 mm` | circle | 1.10 mm |

### `SW2` - LATCH_PWR (`Connector_PinHeader_2.54mm:PinHeader_1x02_P2.54mm_Vertical`)
- **Physical Dimensions**: `3.54 mm × 6.09 mm`
- **Placement on PCB**: `X = 52.50 mm`, `Y = 114.50 mm`, Rotation = `0.0°` (Layer: F.Cu)
- **Total Pads**: 2 (thru_hole)
| Pad # | Local Offset (X, Y) | Pad Size (W × H) | Pad Shape | Hole Drill |
|---|---|---|---|---|
| **1** | `(0.00, 0.00)` | `1.70 × 1.70 mm` | rect | 1.00 mm |
| **2** | `(0.00, 2.54)` | `1.70 × 1.70 mm` | circle | 1.00 mm |

### `U1` - ESP32_DevKit_V1 (`FallSensor:ESP32_DevKit_DOIT_2x15`)
- **Physical Dimensions**: `39.20 mm × 29.00 mm`
- **Placement on PCB**: `X = 127.50 mm`, `Y = 109.86 mm`, Rotation = `180.0°` (Layer: F.Cu)
- **Total Pads**: 30 (thru_hole)
| Pad # | Local Offset (X, Y) | Pad Size (W × H) | Pad Shape | Hole Drill |
|---|---|---|---|---|
| **1** | `(0.00, 0.00)` | `1.70 × 1.70 mm` | rect | 1.00 mm |
| **2** | `(2.54, 0.00)` | `1.70 × 1.70 mm` | circle | 1.00 mm |
| **3** | `(5.08, 0.00)` | `1.70 × 1.70 mm` | circle | 1.00 mm |
| **4** | `(7.62, 0.00)` | `1.70 × 1.70 mm` | circle | 1.00 mm |
| **5** | `(10.16, 0.00)` | `1.70 × 1.70 mm` | circle | 1.00 mm |
| **6** | `(12.70, 0.00)` | `1.70 × 1.70 mm` | circle | 1.00 mm |
| **7** | `(15.24, 0.00)` | `1.70 × 1.70 mm` | circle | 1.00 mm |
| **8** | `(17.78, 0.00)` | `1.70 × 1.70 mm` | circle | 1.00 mm |
| **9** | `(20.32, 0.00)` | `1.70 × 1.70 mm` | circle | 1.00 mm |
| **10** | `(22.86, 0.00)` | `1.70 × 1.70 mm` | circle | 1.00 mm |
| **11** | `(25.40, 0.00)` | `1.70 × 1.70 mm` | circle | 1.00 mm |
| **12** | `(27.94, 0.00)` | `1.70 × 1.70 mm` | circle | 1.00 mm |
| **13** | `(30.48, 0.00)` | `1.70 × 1.70 mm` | circle | 1.00 mm |
| **14** | `(33.02, 0.00)` | `1.70 × 1.70 mm` | circle | 1.00 mm |
| **15** | `(35.56, 0.00)` | `1.70 × 1.70 mm` | circle | 1.00 mm |
| **16** | `(0.00, 25.40)` | `1.70 × 1.70 mm` | circle | 1.00 mm |
| **17** | `(2.54, 25.40)` | `1.70 × 1.70 mm` | circle | 1.00 mm |
| **18** | `(5.08, 25.40)` | `1.70 × 1.70 mm` | circle | 1.00 mm |
| **19** | `(7.62, 25.40)` | `1.70 × 1.70 mm` | circle | 1.00 mm |
| **20** | `(10.16, 25.40)` | `1.70 × 1.70 mm` | circle | 1.00 mm |
| **21** | `(12.70, 25.40)` | `1.70 × 1.70 mm` | circle | 1.00 mm |
| **22** | `(15.24, 25.40)` | `1.70 × 1.70 mm` | circle | 1.00 mm |
| **23** | `(17.78, 25.40)` | `1.70 × 1.70 mm` | circle | 1.00 mm |
| **24** | `(20.32, 25.40)` | `1.70 × 1.70 mm` | circle | 1.00 mm |
| **25** | `(22.86, 25.40)` | `1.70 × 1.70 mm` | circle | 1.00 mm |
| **26** | `(25.40, 25.40)` | `1.70 × 1.70 mm` | circle | 1.00 mm |
| **27** | `(27.94, 25.40)` | `1.70 × 1.70 mm` | circle | 1.00 mm |
| **28** | `(30.48, 25.40)` | `1.70 × 1.70 mm` | circle | 1.00 mm |
| **29** | `(33.02, 25.40)` | `1.70 × 1.70 mm` | circle | 1.00 mm |
| **30** | `(35.56, 25.40)` | `1.70 × 1.70 mm` | circle | 1.00 mm |

### `U2` - Digispark_ATtiny85 (`FallSensor:Digispark_9Pin_RightAngle`)
- **Physical Dimensions**: `26.50 mm × 19.00 mm` (Production Rev 3: 17.5×19.0mm body + 9.0×12.0mm USB tongue)
- **Placement on PCB**: `X = 75.92 mm`, `Y = 119.25 mm`, Rotation = `0.0°` (Layer: F.Cu)
- **Total Pads**: 9 (thru_hole, drill 1.016 mm, pad 1.88 mm)
| Pad # | Function / Signal | Net Name | Local Offset (X, Y) | Board Coord (X, Y) | Pad Shape |
|---|---|---|---|---|---|
| **1** | P5 (Reset) | `unconnected-(U2-P5/RESET-Pad1)` | `(7.00, -7.45)` | `(82.92, 111.80)` | rect |
| **2** | P4 (MIC_SIG) | `Net-(U2-P4)` | `(7.00, -4.91)` | `(82.92, 114.34)` | circle |
| **3** | P3 (USB D+ / NC) | `unconnected-(U2-P3-Pad3)` | `(7.00, -2.37)` | `(82.92, 116.88)` | circle |
| **4** | P2 (PIR_WAKE) | `/PIR_WAKE` | `(7.00, 0.17)` | `(82.92, 119.42)` | circle |
| **5** | P1 (PIR_SIG) | `Net-(PIR1-OUT)` | `(7.00, 2.71)` | `(82.92, 121.96)` | circle |
| **6** | P0 (MIC_WAKE) | `/MIC_WAKE` | `(7.00, 5.25)` | `(82.92, 124.50)` | circle |
| **7** | GND (Ground) | `GND` | `(-3.29, 7.75)` | `(72.63, 127.00)` | circle |
| **8** | VIN (unconnected)| `unconnected-(U2-VIN-Pad8)` | `(-0.75, 7.75)` | `(75.17, 127.00)` | circle |
| **9** | 5V (+3V3 Rail) | `+3V3` | `(-5.83, 7.75)` | `(70.09, 127.00)` | rect |

### `U3` - MT3608_Module (`FallSensor:MT3608_Module`)
- **Physical Dimensions**: `36.00 mm × 17.00 mm` (Silkscreen Envelope: `X` in [74.00, 110.00] mm, `Y` in [51.00, 68.00] mm)
- **Placement on PCB**: `X = 77.25 mm`, `Y = 55.70 mm`, Rotation = `0.0°` (Layer: F.Cu)
- **Total Pads**: 4 (thru_hole, drill 1.20 mm, pad 2.00 mm)
| Pad # | Signal / Function | Net Name | Local Offset (X, Y) | Board Coord (X, Y) | Pad Shape | Hole Drill |
|---|---|---|---|---|---|---|
| **1** | VIN+ (Battery Boost In) | `Net-(U3-VIN+)` | `(0.00, 7.60)` | `(77.25, 63.30)` | rect | 1.20 mm |
| **2** | VIN- (Ground Return) | `GND` | `(0.00, 0.00)` | `(77.25, 55.70)` | circle | 1.20 mm |
| **3** | VOUT+ (+5V System Rail) | `+5V` | `(29.50, 7.60)` | `(106.75, 63.30)` | circle | 1.20 mm |
| **4** | VOUT- (Ground Return) | `GND` | `(29.50, 0.00)` | `(106.75, 55.70)` | circle | 1.20 mm |

### `U4` - TP4056_Module (`FallSensor:TP4056_Module`)
- **Physical Dimensions**: `17.00 mm × 27.00 mm` (Production Direct Standoff Mount, 14.0mm header span)
- **Placement on PCB**: `X = 76.00 mm`, `Y = 103.00 mm`, Rotation = `90.0°` (Layer: F.Cu)
- **Total Pads**: 4 (thru_hole, drill 1.00 mm, pad 1.70 mm)
| Pad # | Signal / Function | Net Name | Local Offset (X, Y) | Board Coord (X, Y) | Pad Shape |
|---|---|---|---|---|---|
| **3** | OUT+ (Positive Load Out) | `Net-(U4-OUT+)` | `(7.00, 0.00)` | `(76.00, 96.00)` | rect |
| **1** | B+ (Battery Positive) | `Net-(BT1-Pin_2)` | `(4.46, 0.00)` | `(76.00, 98.54)` | circle |
| **2** | B- (Battery Negative) | `Net-(BT1-Pin_1)` | `(-4.46, 0.00)` | `(76.00, 107.46)` | circle |
| **4** | OUT- (System Ground) | `GND` | `(-7.00, 0.00)` | `(76.00, 110.00)` | circle |

### `U5` - LM393_Sound_Module (`FallSensor:LM393_Sound_Module`)
- **Physical Dimensions**: `36.00 mm × 15.00 mm` (clean rectangle without potentiometer overhang)
- **Placement on PCB**: `X = 115.50 mm`, `Y = 76.81 mm`, Rotation = `90.0°` (Layer: F.Cu)
- **Acoustic Center of Electret Capsule**: `X = 142.50 mm`, `Y = 73.00 mm` — *Collinear on unified aperture axis $X = 142.50\text{ mm}$*
- **Total Pads**: 4 (thru_hole)
| Pad # | Local Offset (X, Y) | Pad Size (W × H) | Pad Shape | Hole Drill |
|---|---|---|---|---|
| **1** | `(0.00, 0.00)` | `1.70 × 1.70 mm` | rect | 1.00 mm |
| **2** | `(2.54, 0.00)` | `1.70 × 1.70 mm` | circle | 1.00 mm |
| **3** | `(5.08, 0.00)` | `1.70 × 1.70 mm` | circle | 1.00 mm |
| **4** | `(7.62, 0.00)` | `1.70 × 1.70 mm` | circle | 1.00 mm |

### `U6` - LoadSwitch_DBVT (Dual Strategy: Prototype 2.54mm THT Header vs Production SOT-23-6 SMD)

> **Design Note**: To facilitate prototyping and hand-assembly without microscope SMD soldering equipment, the current prototype board accommodates a **2.54mm Through-Hole (THT) daughterboard socket**. The ultra-compact **SOT-23-6 SMD footprint** is permanently preserved in the library (`FallSensor.pretty/SOT-23-6.kicad_mod`) for the next-generation fully automated SMD production iteration.

#### Option A: Production SMD Iteration (`FallSensor:SOT-23-6` / `Package_TO_SOT_SMD:SOT-23-6`)
- **Package Type**: Surface Mount (SMD 6-lead SOT-23)
- **Physical Dimensions**: `2.90 mm × 2.80 mm` (Courtyard: `4.10 mm × 3.40 mm`)
- **Lead Pitch**: `0.95 mm`
- **Pads**: 6 (smd roundrect `1.32 × 0.60 mm`)
- **Library Location**: Saved in `FallSensor.pretty/SOT-23-6.kicad_mod`

| Pad # | Function | Net | Description |
|---|---|---|---|
| **1** | VIN | `+5V` | 5V supply input from MT3608 boost converter |
| **2** | GND | `GND` | Ground return |
| **3** | ON / EN | `/RADAR_EN` | Active-high enable from ESP32 GPIO27 |
| **4** | GND | `GND` | Thermal ground return |
| **5** | GND | `GND` | Thermal ground return |
| **6** | VOUT | `Net-(RADAR1-VIN)` | Switched 5V power output to C1001 Radar module |

#### Option B: Prototype Hand-Assembly Daughterboard Socket (`FallSensor:PinHeader_2x03_P2.54mm_Vertical` / `FallSensor:DIP-6_W7.62mm`)
- **Package Type**: Through-Hole Technology (THT 2.54mm pin header / DIP-6 socket)
- **Physical Dimensions**: `5.08 mm × 7.62 mm` (2 rows of 3 pins)
- **Pin Pitch**: `2.54 mm (0.1")`
- **Row Spacing**: `2.54 mm` (Pin Header) or `7.62 mm (300 mil)` (DIP-6 Socket)
- **Mounting**: Hand-soldered female/male header socket accepting a plug-in SOT-23-to-DIP daughterboard breakout
- **Library Location**: Saved in `FallSensor.pretty/PinHeader_2x03_P2.54mm_Vertical.kicad_mod` and `FallSensor.pretty/DIP-6_W7.62mm.kicad_mod`

### `U7` - Buck Converter (`FallSensor:LM2596_Module`)
- **Physical Dimensions**: `43.18 mm × 21.08 mm` (Silkscreen Envelope: `X` in [50.53, 71.62] mm, `Y` in [50.66, 93.84] mm)
- **Placement on PCB**: `X = 68.50 mm`, `Y = 52.50 mm`, Rotation = `-90.0°` (Layer: F.Cu)
- **Total Pads**: 4 (thru_hole, drill 1.50 mm, pad 3.00 mm)
| Pad # | Signal / Function | Net Name | Board Coord (X, Y) | Pad Shape | Hole Drill |
|---|---|---|---|---|---|
| **1** | IN+ (+5V Power In) | `+5V` | `(69.65, 52.50)` | rect | 1.50 mm |
| **2** | IN- (Ground Return) | `GND` | `(52.50, 52.50)` | circle | 1.50 mm |
| **3** | OUT+ (+3V3 Regulated Out)| `+3V3` | `(69.65, 92.00)` | circle | 1.50 mm |
| **4** | OUT- (Ground Return) | `GND` | `(52.50, 92.00)` | circle | 1.50 mm |

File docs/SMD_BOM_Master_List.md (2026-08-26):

# Production SMD PCB - Master Component Selection & BOM List

This master document specifies all surface-mount device (SMD) integrated circuits, protection components, connectors, and passives required to convert the prototype into a commercial, high-reliability PCB for the Fall Sensor system.

---

## 1. Core Microcontrollers & Processing

| Ref Designator | Function | Recommended SMD Part Number | Package | Description / Justification |
|---|---|---|---|---|
| **U1** | Main Microcontroller (Wi-Fi/BLE) | **ESP32-WROOM-32E-N4** | SMD Module (18×25.5mm) | FCC/CE pre-certified module with integrated 3D PCB antenna, 4MB Flash. Avoids raw chip RF tuning complexity. |
| **U2** | Sentinel Co-Processor | **ATtiny85-20SU** | SOIC-8 (150mil) | Ultra-low power co-processor (<0.2µA sleep). Manages PIR & MIC interrupts to keep ESP32 asleep. |

---

## 2. Power Management & Charger ICs

| Ref Designator | Function | Recommended SMD Part Number | Package | Description / Justification |
|---|---|---|---|---|
| **U4A** (Option 1) | Li-Ion Charger w/ Power-Path | **Texas Instruments BQ24075RGTR** | VQFN-16 (3×3mm) | **Gold Standard:** 1.5A charger with Dynamic Power-Path. Runs system off USB power while independently charging battery. |
| **U4B** (Option 2) | Standalone Li-Ion Charger | **Texas Instruments BQ24040DSQR** / **BQ24050** | WSON-10 (2×2mm) | 800mA Linear Charger IC with 30V input tolerance, auto-charge termination, and NTC thermistor pin. |
| **U4C** (Option 3) | Integrated Power Bank PMIC | **Injoinic IP5306** | SOP-8 | **All-in-One Budget Option:** Combines 2.1A Charger + 5V 2.4A Synchronous Boost + 4-LED Fuel Gauge in 1 IC. |
| **U3** | 3.7V to 5V Step-Up Boost | **MT3608** / **SX1308** | SOT-23-6 | High-frequency 1.2MHz boost converter to generate 5V rail for Radar sensor. |
| **U6** | 3.3V LDO Regulator | **TLV75533PDBVR** (or **AMS1117-3.3**) | SOT-23-5 | Ultra-low quiescent current (31µA) 500mA 3.3V LDO regulator for ESP32 and logic. |

---

## 3. Battery Protection Circuit Module (PCM) & Safety

| Ref Designator | Function | Recommended SMD Part Number | Package | Description / Justification |
|---|---|---|---|---|
| **U8** | Over-Charge / Under-Voltage IC | **DW01A** (or **DW01-P**) | SOT-23-6 | Precision battery protection controller. Cuts discharge at 2.8V (UVLO) and charge at 4.25V. |
| **Q2** | Dual N-Channel Power MOSFET | **FS8205A** | TSSOP-8 | High-density 20V 6A dual N-MOSFET driven by DW01A for high-side/low-side disconnect. |
| **Q3** | Reverse Polarity Protection | **AO3401A** (or **Si2301CDS**) | SOT-23 | P-Channel MOSFET on battery positive rail to prevent catastrophic damage if battery leads are reversed. |
| **D2** | USB-C ESD Protection Array | **USBLC6-2SC6** | SOT-23-6 | Low-capacitance ESD protection diode array for VBUS, D+, D- lines (15kV ESD protection). |
| **NTC1** | Battery Thermal Sensor | **10K NTC Thermistor** (0805) | 0805 | Placed adjacent to battery holder, wired to Charger TS pin to halt charging outside 0°C–45°C. |

---

## 4. Sensors & Acoustic Detection Circuitry

| Ref Designator | Function | Recommended SMD Part Number | Package | Description / Justification |
|---|---|---|---|---|
| **RADAR1** | Radar Interface Header | **2.54mm Pitch 1x6 Header** (or Direct Solder Pads) | SMT / TH | Interfaces C1001 60GHz or LD2410 24GHz Radar module. |
| **U5** | Acoustic Dual Comparator | **LM393G** / **LM393LV** | SOIC-8 | Dual differential comparator for LM393 sound thud sensor module. |
| **MIC1** | Electret Microphone | **CMA-4544PF-W** (or **SMD Mic**) | 6mm DIP/SMD | Electret microphone capsule for sound impulse pickup. |
| **PIR1** | Passive Infrared Sensor | **AS312** (or **AM312 Element**) | SOT-23-6 / TO-5 | Digital PIR sensor element with integrated delay controller. |
| **Q1** | Radar Power-Gating MOSFET | **AO3400A** (or **BSS138**) | SOT-23 | N-Channel MOSFET controlled by GPIO 27 to cut 5V power to Radar when sleeping. |

---

## 5. Battery Connectors, Switches & User Interface

| Ref Designator | Function | Recommended SMD Part Number | Package | Description / Justification |
|---|---|---|---|---|
| **J1** | Battery Cable Connector | **JST-PH-2.0mm S2B-PH-K-S** | SMT Right-Angle | **Industry Standard:** 2-pin keyed connector for Li-Ion / LiPo battery packs. |
| **J2** (Alt) | On-Board 21700 Battery Clip | **Keystone 1048** / **1042** | SMT Clips | Mounted directly on back of PCB for wireless 21700/18650 cell insertion. |
| **J3** | USB-C Power / Charging Input | **TYPE-C-31-M-12** (16-Pin) | SMT Mid-Mount | 16-pin USB-C receptacle for 5V power input. Uses 5.1k pull-down resistors on CC1/CC2 lines. |
| **SW2** | Main System Power Switch | **SK-12D07** / **SS-12D00** | SMT 3-Pin | Low-profile SMT slide switch. |
| **SW1** | Sync / Manual Wake Button | **EVQ-P7A01K** (3×4mm) | SMT Tactile | Momentary push button connected to GPIO 33. |
| **D1** | Fall Siren Alarm LED | **0805 Red LED** | 0805 SMT | High-brightness red LED driven by GPIO 19. |
| **D3** | Charge Status LED | **0805 Green/Amber Dual LED** | 0805 SMT | Driven by STAT1/STAT2 pins of BQ24075 / TP4056. |

---

## 6. Passives & Value Specification

| Component | Value / Rating | Package | Purpose |
|---|---|---|---|
| **R1, R2** | **1MΩ (1%)** | 0805 | Battery Voltage Divider (connected to GPIO 34). 1MΩ values reduce battery drain to <1.8µA! |
| **R3** | **270Ω** | 0805 | Current-limiting resistor for Fall Alarm LED. |
| **R4** | **10kΩ** | 0805 | Pull-down resistor on MOSFET Gate (GPIO 27). |
| **R5, R6** | **5.1kΩ (1%)** | 0603 | CC1 & CC2 pull-down resistors on USB-C receptacle (required for USB-C PD power delivery). |
| **C1, C2** | **10µF 16V Ceramic** | 0805 | Decoupling capacitors for LDO 3.3V and 5V boost rails. |
| **C3, C4** | **100nF 16V Ceramic** | 0603 | High-frequency bypass capacitors for ESP32 and ATtiny85 VCC pins. |

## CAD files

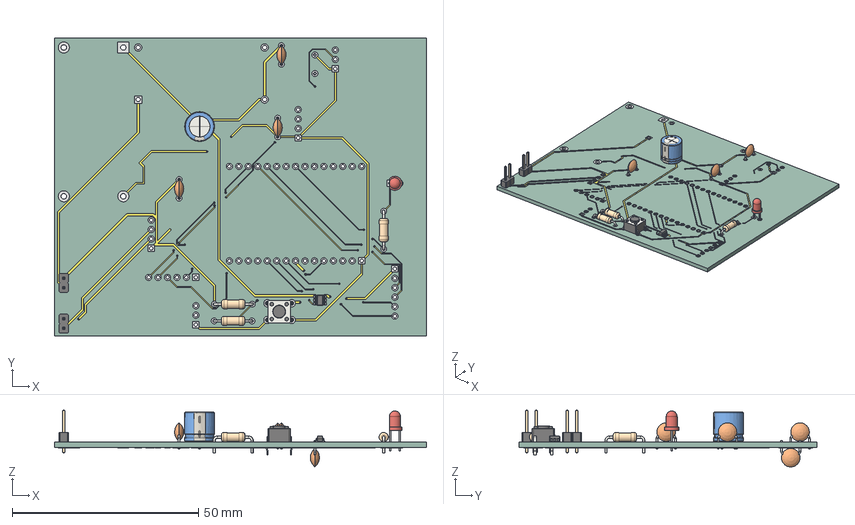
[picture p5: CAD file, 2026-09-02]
hardware/fall_sensor_full_assembly.step
100.0 x 80.0 x 15.3 mm
R_Axial_DIN0207_L63mm_D25mm_P1016mm_Horizontal x 3
C_Disc_D50mm_W25mm_P500mm x 4
PinHeader_1x02_P254mm_Vertical x 2
CP_Radial_D80mm_P350mm
LED_D3.0mm
SW_PUSH_6mm
SOT-23-6
fall_sensor_copper
fall_sensor_pad
fall_sensor_via
fall_sensor_PCB

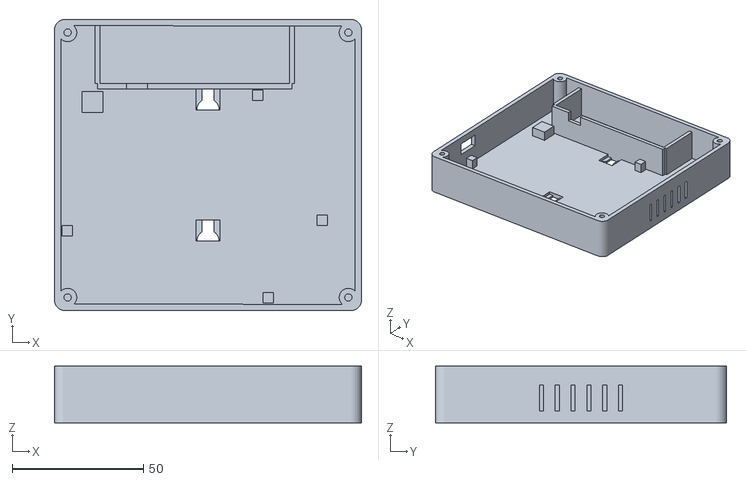
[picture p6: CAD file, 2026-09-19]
enclosure/fall_sensor_enclosure_base.stl
116.8 x 110.8 x 21.5

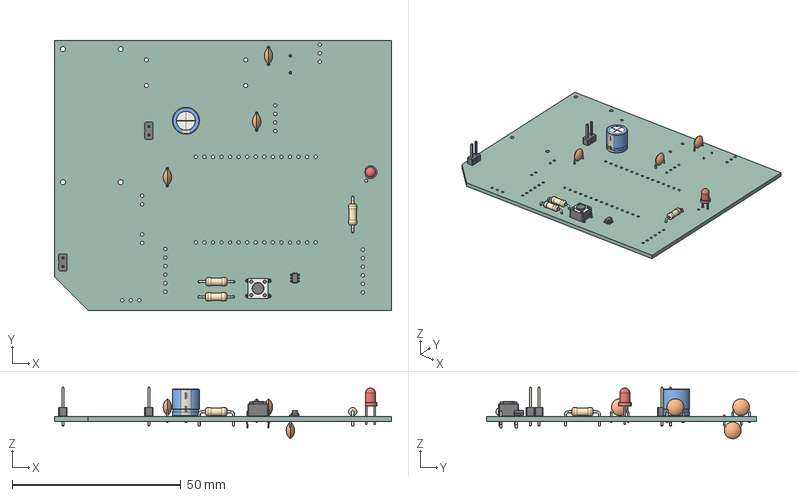
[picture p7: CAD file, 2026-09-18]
hardware/fall_sensor_board_dummy.step
100.0 x 80.0 x 15.3 mm
R_Axial_DIN0207_L63mm_D25mm_P1016mm_Horizontal x 3
C_Disc_D50mm_W25mm_P500mm x 4
PinHeader_1x02_P254mm_Vertical x 2
CP_Radial_D80mm_P350mm
LED_D3.0mm
SW_PUSH_6mm
SOT-23-6
fall_sensor_PCB

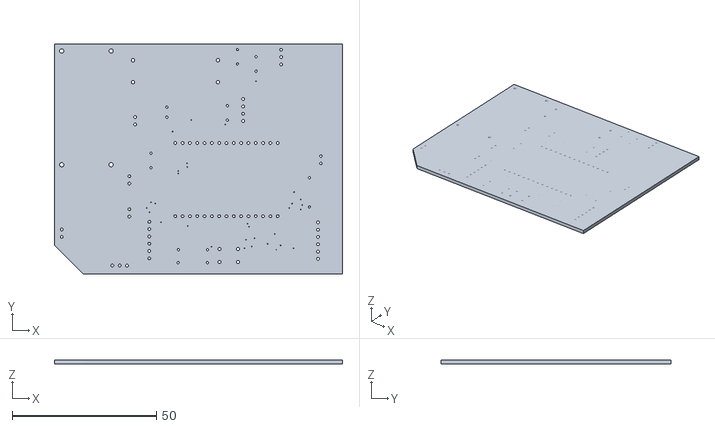
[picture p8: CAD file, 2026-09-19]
enclosure/fall_sensor_pcb_dummy.stl
100.0 x 80.0 x 1.51

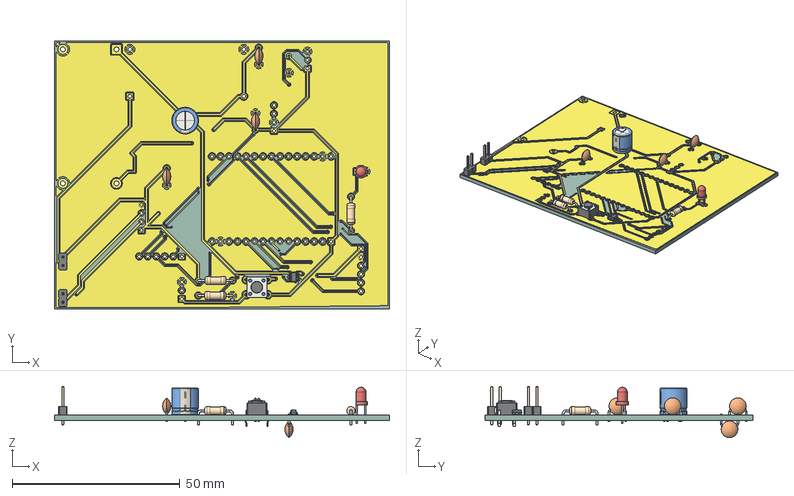
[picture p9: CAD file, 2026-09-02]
hardware/fall_sensor.step
100.0 x 80.0 x 15.3 mm
R_Axial_DIN0207_L63mm_D25mm_P1016mm_Horizontal x 3
C_Disc_D50mm_W25mm_P500mm x 4
PinHeader_1x02_P254mm_Vertical x 2
CP_Radial_D80mm_P350mm
LED_D3.0mm
SW_PUSH_6mm
SOT-23-6
fall_sensor_copper
fall_sensor_PCB

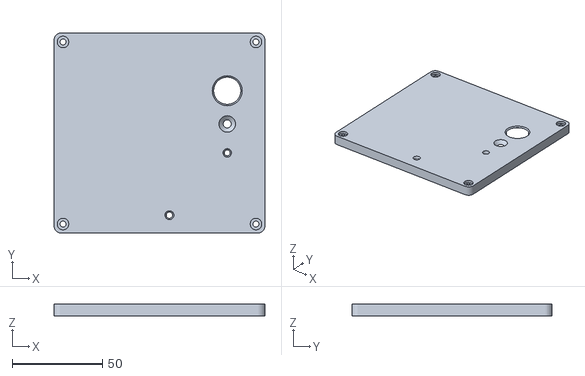
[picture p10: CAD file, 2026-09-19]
enclosure/fall_sensor_enclosure_lid.stl
116.8 x 110.8 x 6.50

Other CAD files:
enclosure/fall_sensor_enclosure.blend

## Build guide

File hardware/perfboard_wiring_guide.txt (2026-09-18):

================================================================================
FALL SENSOR SYSTEM - PERFBOARD / PROTOTYPE WIRING DIRECTORY
================================================================================
Based on KiCad Carrier PCB: fall_sensor.kicad_pcb
Total Connected Nets: 21 | Total Components: 21

This guide provides a functional, point-to-point connection list for assembling 
the Fall Sensor system on a prototype perfboard or breadboard before finalizing 
the printed circuit board.

--------------------------------------------------------------------------------
SECTION 1: COMPONENT & MODULE PINOUT REFERENCE
--------------------------------------------------------------------------------
1. U1: ESP32 DevKit V1 (30-Pin NodeMCU ESP-WROOM-32)
   - Left Row (Pins 1-15):
     Pin 1:  3V3              Pin 9:  GPIO25 (PRESENCE_PIN)
     Pin 2:  EN (NC)          Pin 10: GPIO26 (FALL_PIN)
     Pin 3:  GPIO36/VP (NC)   Pin 11: GPIO27 (RADAR_EN)
     Pin 4:  GPIO39/VN (NC)   Pin 12: GPIO14 (NC)
     Pin 5:  GPIO34 (BATT_ADC)Pin 13: GPIO12 (NC)
     Pin 6:  GPIO35 (NC)      Pin 14: GND
     Pin 7:  GPIO32 (NC)      Pin 15: GPIO13 (PIR_WAKE)
     Pin 8:  GPIO33 (SYNC_BTN)

   - Right Row (Pins 16-30):
     Pin 16: VIN (NC)         Pin 24: GPIO18 (NC)
     Pin 17: GND              Pin 25: GPIO5 (NC)
     Pin 18: GPIO23 (NC)      Pin 26: GPIO17 (RADAR_TX)
     Pin 19: GPIO22 (NC)      Pin 27: GPIO16 (RADAR_RX)
     Pin 20: TX0 (NC)         Pin 28: GPIO4 (MIC_WAKE)
     Pin 21: RX0 (NC)         Pin 29: GPIO2 (NC)
     Pin 22: GPIO21 (NC)      Pin 30: GPIO15 (NC)
     Pin 23: GPIO19 (FALL_LED)

2. U2: Digispark ATtiny85 (Low-Power Sensor Co-Processor)
   - Pin 1: P5 / RST (NC)
   - Pin 2: P4 (MIC_SIG Input from LM393 DO)
   - Pin 3: P3 (NC)
   - Pin 4: P2 (PIR_WAKE Output to ESP32 GPIO13)
   - Pin 5: P1 (PIR_SIG Input from AM312 OUT)
   - Pin 6: P0 (MIC_WAKE Output to ESP32 GPIO4)
   - Pin 7: GND
   - Pin 8 / 9: VIN / 5V (Connected to +3.3V Logic Rail)

3. U3: MT3608 Step-Up Boost Converter Module
   - Pin 1: VIN+ (Battery switched input via SW2)
   - Pin 2: VIN- / GND
   - Pin 3: VOUT+ (Boosted +5.0V output, trimpot-adjusted)
   - Pin 4: GND

4. U4: TP4056 LiPo Battery Charging & Protection Module
   - Pin 1: BAT+ (Direct connection to BT1 Pad 2)
   - Pin 2: BAT- (Direct connection to BT1 Pad 1)
   - Pin 3: OUT+ (Protected battery output to SW2, C1, and R1)
   - Pin 4: OUT- / GND (Common system ground)

5. U5: LM393 Sound Detection Sensor Module
   - Pin 1: VCC (+3.3V rail)
   - Pin 2: GND
   - Pin 3: DO (Digital Output to ATtiny85 P4)
   - Pin 4: AO (Analog Output, NC)

6. U6: Load Switch (SOT-23-6 DBVT or discrete P-MOSFET circuit)
   - Pin 1: VIN (+5V boosted rail)
   - Pins 2, 4, 5: GND
   - Pin 3: EN (Enable control from ESP32 GPIO27)
   - Pin 6: VOUT (Switched +5V power to Radar VIN)

7. U7: LM2596 Step-Down Buck Converter Module
   - Pin 1: IN+ (+5V from MT3608 VOUT+)
   - Pin 2: IN- (GND)
   - Pin 3: OUT+ (+3.3V high-current logic rail, trimpot-adjusted)
   - Pin 4: OUT- (GND)

8. RADAR1: C1001 60GHz mmWave Fall Detection Radar
   - Pin 1: VIN (Switched +5V from U6 Pin 6)
   - Pin 2: GND
   - Pin 3: TX (UART TX to ESP32 GPIO17/RX)
   - Pin 4: RX (UART RX to ESP32 GPIO16/TX)
   - Pin 5: OUT1 (Digital Presence Detection to ESP32 GPIO25)
   - Pin 6: OUT2 (Digital Fall Alert to ESP32 GPIO26)

9. PIR1: AM312 Mini PIR Motion Sensor
   - Pin 1: VCC (+3.3V rail)
   - Pin 2: OUT (Digital Motion signal to ATtiny85 P1)
   - Pin 3: GND

10. Switches, Battery & UI Components:
   - BT1: 18650 Battery Solder Pads (Pin 1: BAT-, Pin 2: BAT+)
   - SW1: Tactile Pushbutton (SYNC button)
   - SW2: SPST Power Toggle Switch (Main System Power)
   - D1:  Status LED (Pin 1: Anode A, Pin 2: Cathode K)
   - R1:  100kΩ Resistor (Battery Divider High-Side)
   - R2:  100kΩ Resistor (Battery Divider Low-Side)
   - R3:  270Ω Resistor (LED Current Limiter)
   - C1:  10µF Capacitor (Battery rail buffer)
   - C3:  470µF 16V Electrolytic Capacitor (Radar +5V pulse buffer)
   - C4:  22µF Capacitor (+5V filter)
   - C7:  0.1µF Ceramic Capacitor (+3.3V decoupling)
   - C8:  0.1µF Ceramic Capacitor (+3.3V decoupling)

--------------------------------------------------------------------------------
SECTION 2: FUNCTIONAL WIRING NETLIST (GROUP BY GROUP)
--------------------------------------------------------------------------------

================================================================================
GROUP 1: COMMON GROUND BUS (GND) - Connect all 21 points together
================================================================================
Create a sturdy bare-copper ground rail along the perfboard. Solder each point:
  1.  U4 TP4056       Pin 4  (OUT-)
  2.  U3 MT3608       Pin 2  (VIN-)
  3.  U3 MT3608       Pin 4  (GND)
  4.  U7 LM2596       Pin 2  (IN-)
  5.  U7 LM2596       Pin 4  (OUT-)
  6.  U1 ESP32        Pin 14 (GND)
  7.  U1 ESP32        Pin 17 (GND)
  8.  U2 ATtiny85     Pin 7  (GND)
  9.  PIR1 AM312      Pin 3  (GND)
  10. U5 LM393        Pin 2  (GND)
  11. RADAR1 C1001    Pin 2  (GND)
  12. U6 LoadSwitch   Pin 2  (GND)
  13. U6 LoadSwitch   Pin 4  (GND)
  14. U6 LoadSwitch   Pin 5  (GND)
  15. D1 Status LED   Pin 2  (Cathode K, short leg / flat side)
  16. R2 Resistor     Pin 2  (Low side of 100kΩ divider)
  17. C1 Capacitor    Pin 2  (10µF negative)
  18. C3 Capacitor    Pin 2  (470µF electrolytic negative stripe)
  19. C4 Capacitor    Pin 2  (22µF negative)
  20. C7 Capacitor    Pin 2  (0.1µF ceramic ground)
  21. C8 Capacitor    Pin 2  (0.1µF ceramic ground)

================================================================================
GROUP 2: BATTERY & CHARGING PATH
================================================================================
  1. BT1 Battery Lead (+) [Pin 2] ---------> U4 TP4056 BAT+ [Pin 1]
  2. BT1 Battery Lead (-) [Pin 1] ---------> U4 TP4056 BAT- [Pin 2]
     (Keep these two leads thick and direct to ensure low ESR during charging)

================================================================================
GROUP 3: PROTECTED BATTERY OUTPUT & MAIN POWER SWITCH
================================================================================
  All these 4 points connect together:
  - U4 TP4056 OUT+ [Pin 3]
  - C1 Capacitor (10µF) Positive [Pin 1]
  - R1 Resistor (100kΩ) [Pin 1]
  - SW2 Power Switch Terminal 1 [Pin 1]

  Then from switch:
  - SW2 Power Switch Terminal 2 [Pin 2] ---> U3 MT3608 VIN+ [Pin 1]
  (Closing SW2 connects battery power into the boost converter)

================================================================================
GROUP 4: BOOSTED +5V POWER RAIL (Adjust MT3608 to 5.00V before connecting load)
================================================================================
  All these 5 points connect together:
  - U3 MT3608 VOUT+ [Pin 3]
  - U7 LM2596 IN+ [Pin 1]
  - U6 LoadSwitch VIN [Pin 1]
  - C3 Capacitor (470µF 16V) Positive [Pin 1]
  - C4 Capacitor (22µF) Positive [Pin 1]
  (C3 absorbs current transients when the mmWave radar sweeps)

================================================================================
GROUP 5: REGULATED +3.3V LOGIC RAIL (Adjust LM2596 to 3.30V before connecting)
================================================================================
  All these 8 points connect together:
  - U7 LM2596 OUT+ [Pin 3]
  - U1 ESP32 3V3 [Pin 1]
  - U2 ATtiny85 VCC/VIN [Pin 9 / Pin 8]
  - PIR1 AM312 VCC [Pin 1]
  - U5 LM393 Sound VCC [Pin 1]
  - SW1 SYNC Pushbutton Terminal 2 [Pin 2]
  - C7 Capacitor (0.1µF) [Pin 1]
  - C8 Capacitor (0.1µF) [Pin 1]

================================================================================
GROUP 6: BATTERY VOLTAGE MONITORING DIVIDER (BATT_ADC)
================================================================================
  Connect these 3 points together:
  - R1 Resistor (100kΩ) Pin 2
  - R2 Resistor (100kΩ) Pin 1
  - U1 ESP32 GPIO34 [Pin 5]
  (R1 is tied to battery OUT+, R2 is tied to GND; mid-point gives V_batt / 2)

================================================================================
GROUP 7: SENSOR WAKEUP & CO-PROCESSOR SIGNALS
================================================================================
  1. PIR Signal:
     - PIR1 AM312 OUT [Pin 2] -------------> U2 ATtiny85 Pin 5 (P1)

  2. Acoustic / Sound Signal:
     - U5 LM393 Sound DO [Pin 3] ----------> U2 ATtiny85 Pin 2 (P4)

  3. Co-Processor Wakeup Lines to ESP32:
     - U2 ATtiny85 Pin 4 (P2) -------------> U1 ESP32 GPIO13 [Pin 15] (PIR_WAKE)
     - U2 ATtiny85 Pin 6 (P0) -------------> U1 ESP32 GPIO4  [Pin 28] (MIC_WAKE)

================================================================================
GROUP 8: C1001 mmWAVE RADAR INTERFACE & POWER GATING
================================================================================
  1. Radar Power Switch:
     - U1 ESP32 GPIO27 [Pin 11] -----------> U6 LoadSwitch EN [Pin 3]
     - U6 LoadSwitch VOUT [Pin 6] ---------> RADAR1 C1001 VIN [Pin 1]
     (ESP32 drives GPIO27 HIGH to energize the radar module)

  2. Radar UART Communications:
     - RADAR1 C1001 TX [Pin 3] ------------> U1 ESP32 GPIO17 [Pin 26] (RX2)
     - RADAR1 C1001 RX [Pin 4] ------------> U1 ESP32 GPIO16 [Pin 27] (TX2)

  3. Radar Real-Time Hardware Alert Lines:
     - RADAR1 C1001 OUT1 [Pin 5] ----------> U1 ESP32 GPIO25 [Pin 9]  (PRESENCE)
     - RADAR1 C1001 OUT2 [Pin 6] ----------> U1 ESP32 GPIO26 [Pin 10] (FALL)

================================================================================
GROUP 9: STATUS INDICATORS & USER CONTROLS
================================================================================
  1. Status LED:
     - U1 ESP32 GPIO19 [Pin 23] -----------> R3 Resistor (270Ω) Pin 1
     - R3 Resistor (270Ω) Pin 2 -----------> D1 Status LED Pin 1 (Anode A)
     (D1 Cathode connects to common Ground)

  2. SYNC Pushbutton:
     - SW1 SYNC Button Pin 1 --------------> U1 ESP32 GPIO33 [Pin 8]
     (SW1 Pin 2 is connected to +3.3V rail. Pressing button pulls GPIO33 HIGH)

--------------------------------------------------------------------------------
SECTION 3: PERFBOARD STEP-BY-STEP BRING-UP CHECKLIST
--------------------------------------------------------------------------------
STEP 1: POWER SUPPLY CALIBRATION (CRITICAL - DO NOT SKIP)
  1. Wire ONLY the battery path, SW2, MT3608, and LM2596. DO NOT connect ESP32, 
     ATtiny85, or any sensors yet!
  2. Insert battery and toggle SW2 ON.
  3. Measure MT3608 VOUT+ with a digital multimeter:
     - Adjust the tiny brass screw on the MT3608 trimpot until output is EXACTLY 5.00V.
  4. Measure LM2596 OUT+ with a digital multimeter:
     - Adjust the trimpot on the LM2596 until output is EXACTLY 3.30V.
  5. Toggle SW2 OFF.

STEP 2: GROUND & RAILS CONTINUITY CHECK
  1. With power OFF, test continuity with multimeter beeper across all GND points.
  2. Verify NO short circuit between GND and +5V rail (resistance should be > 10kΩ).
  3. Verify NO short circuit between GND and +3.3V rail (resistance should be > 10kΩ).
  4. Verify NO short circuit between +5V and +3.3V rails.

STEP 3: POPULATE MCUs & SENSORS
  1. Solder or plug in U1 ESP32 and U2 ATtiny85 into socket headers.
  2. Plug in PIR1 and LM393 modules.
  3. Power on and verify 3.3V is present on ESP32 3V3 pin and ATtiny85 VCC pin.
  4. Test battery voltage divider at ESP32 GPIO34 (should read approx. 1.8V-2.1V).

STEP 4: RADAR MODULE INTEGRATION
  1. Connect C1001 Radar header.
  2. When ESP32 boots and pulls GPIO27 HIGH, verify 5.0V appears on Radar VIN pin.
  3. Verify UART communication and falling edge detection signals.
================================================================================

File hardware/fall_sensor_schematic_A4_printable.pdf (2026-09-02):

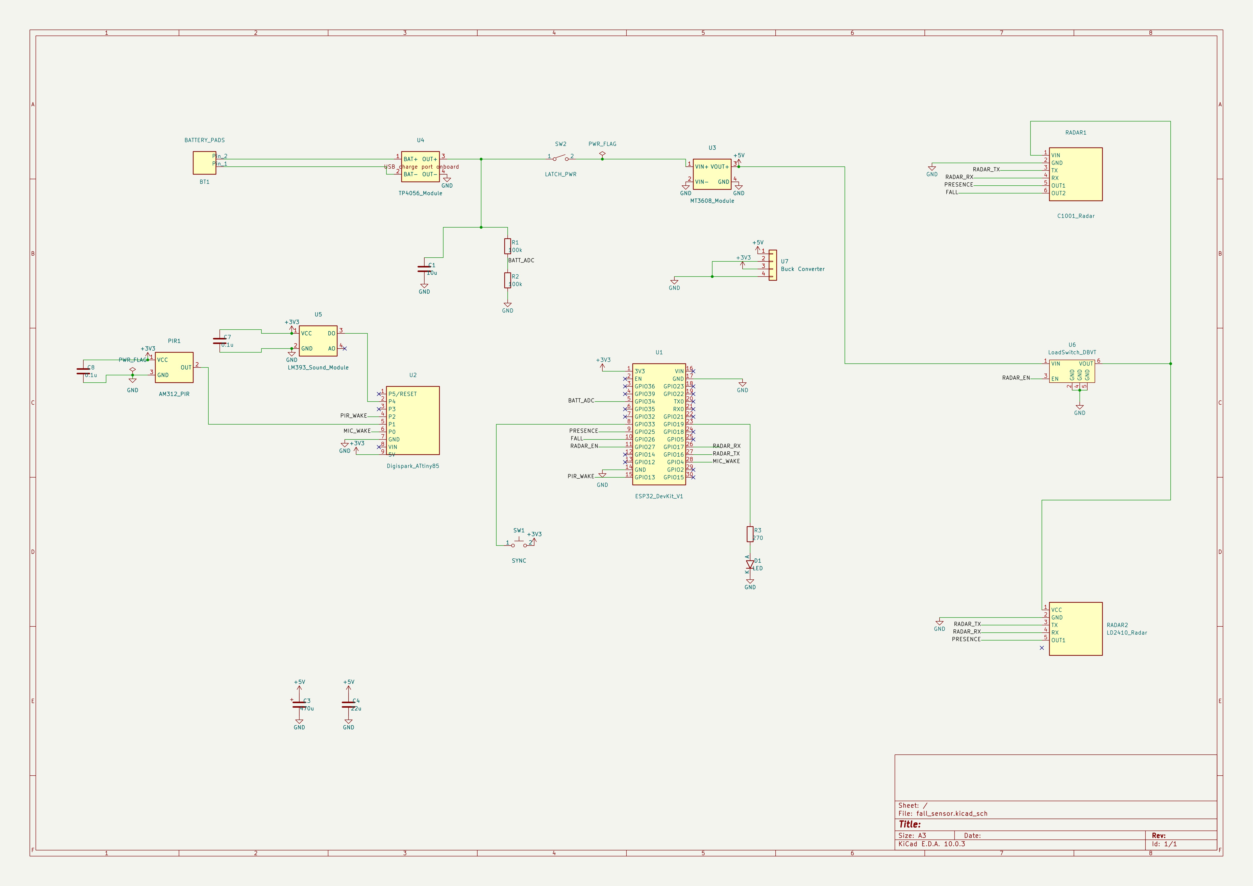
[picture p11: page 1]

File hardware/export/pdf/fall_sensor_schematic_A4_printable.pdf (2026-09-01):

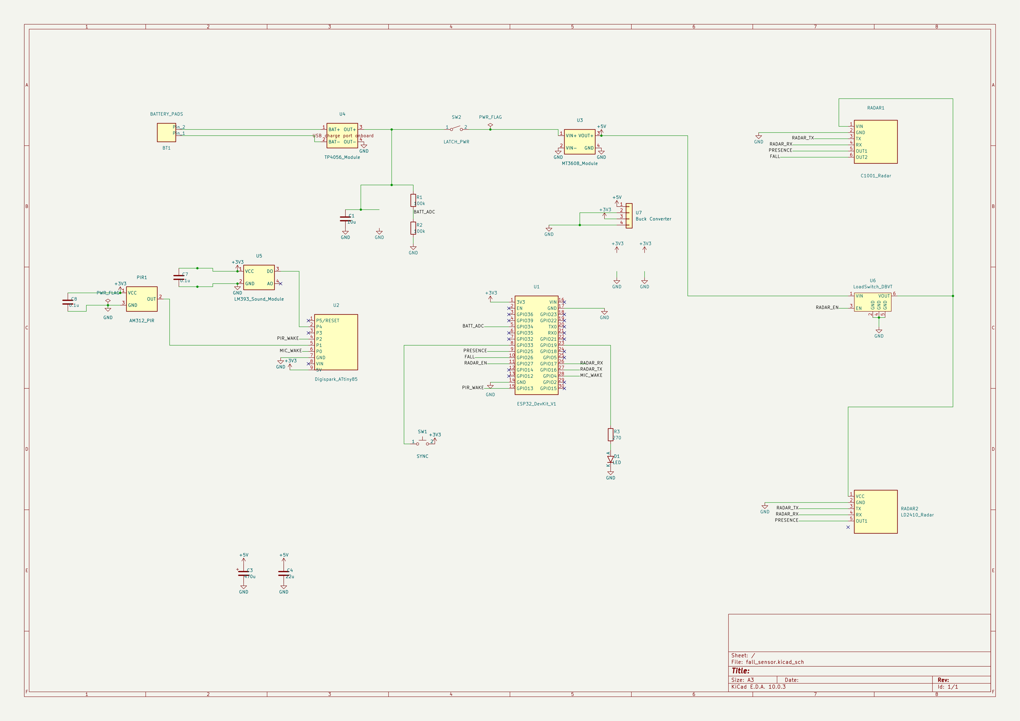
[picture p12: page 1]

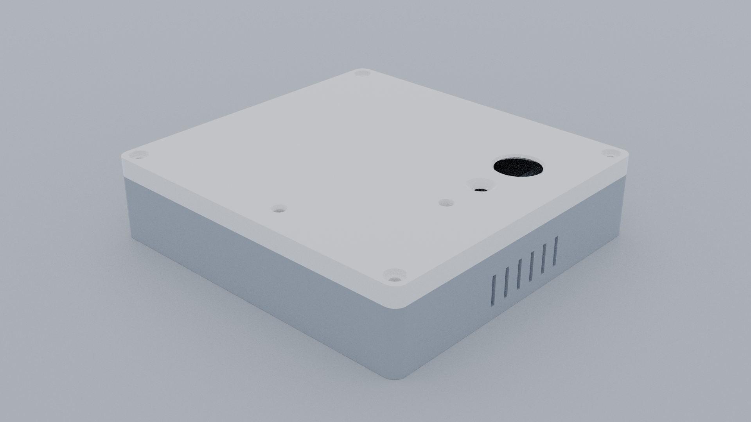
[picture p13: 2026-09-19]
enclosure/fall_sensor_enclosure_assembled_hero.png

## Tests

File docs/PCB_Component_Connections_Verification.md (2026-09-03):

# 🔌 Fall Sensor System — Master Component Pinout & Net Connection List

> **PCB Revision:** Rev A (Prototype) | **Total Components:** 21 | **DRC Status:** 0 Errors, 0 Unconnected Nets

Use this document to manually verify each connection on the physical PCB or schematic.

---

## 1. 🔋 Power Management Subsystem

### `BT1` — Battery Input Connector (1S Li-Ion 3.7V)
| Pin # | Pin Name | Connected Net | Destination / Purpose |
|---|---|---|---|
| **Pin 1** | BAT- | `Net-(BT1-Pin_1)` | Connects to TP4056 `BAT-` (Pin 2) |
| **Pin 2** | BAT+ | `Net-(BT1-Pin_2)` | Connects to TP4056 `BAT+` (Pin 1) |

---

### `U4` — TP4056 Li-Ion Charger Module
| Pin # | Pin Name | Connected Net | Destination / Purpose |
|---|---|---|---|
| **Pin 1** | BAT+ | `Net-(BT1-Pin_2)` | Li-Ion Battery Positive terminal |
| **Pin 2** | BAT- | `Net-(BT1-Pin_1)` | Li-Ion Battery Negative terminal |
| **Pin 3** | OUT+ | `Net-(U4-OUT+)` | Protected raw battery output $\rightarrow$ SW2 (Pin 1), R1 (Pin 1), C1 (Pin 1) |
| **Pin 4** | OUT- | `GND` | Common Ground Plane |

---

### `SW2` — Main Latching Power Switch
| Pin # | Pin Name | Connected Net | Destination / Purpose |
|---|---|---|---|
| **Pin 1** | Input | `Net-(U4-OUT+)` | Raw battery voltage from TP4056 `OUT+` |
| **Pin 2** | Output | `Net-(U3-VIN+)` | Switched battery power to MT3608 Boost `VIN+` |

---

### `U3` — MT3608 Boost Converter (3.7V $\rightarrow$ 5.0V Rail)
| Pin # | Pin Name | Connected Net | Destination / Purpose |
|---|---|---|---|
| **Pin 1** | VIN+ | `Net-(U3-VIN+)` | Switched battery input from SW2 (Pin 2) |
| **Pin 2** | VIN- | `GND` | Common Ground Plane |
| **Pin 3** | VOUT+ | `+5V` | Regulated **+5V Main System Power Rail** (feeds C3, C4, U6 Pin 1, U7 Pin 1) |
| **Pin 4** | GND | `GND` | Common Ground Plane |

---

### `U7` — Buck Converter Step-Down (5.0V $\rightarrow$ 3.3V Rail)
| Pin # | Pin Name | Connected Net | Destination / Purpose |
|---|---|---|---|
| **Pin 1** | IN+ | `+5V` | +5V Rail from MT3608 Boost |
| **Pin 2** | GND | `GND` | Common Ground Plane |
| **Pin 3** | OUT+ | `+3V3` | Regulated **+3.3V Main System Power Rail** (feeds ESP32, ATtiny85, LM393, PIR1, SW1, C7, C8) |
| **Pin 4** | GND | `GND` | Common Ground Plane |

---

## 2. 🧠 Microcontrollers & Co-Processors

### `U1` — ESP32 DevKit V1 (Main Microcontroller)
| Pin # | Pin Label | Connected Net | Destination / Function |
|---|---|---|---|
| **Pin 1** | `3V3` | `+3V3` | Primary +3.3V power input from U7 |
| **Pin 2** | `EN` | *Unconnected* | Handled internally by DevKit onboard reset |
| **Pin 3** | `GPIO36 (VP)` | *Unconnected* | Floating |
| **Pin 4** | `GPIO39 (VN)` | *Unconnected* | Floating |
| **Pin 5** | `GPIO34` | `/BATT_ADC` | Battery Voltage Divider midpoint (R1/R2) |
| **Pin 6** | `GPIO35` | *Unconnected* | Floating |
| **Pin 7** | `GPIO32` | *Unconnected* | Floating |
| **Pin 8** | `GPIO33` | `Net-(U1-GPIO33)` | Tactile Sync / Disarm Push Button (SW1) |
| **Pin 9** | `GPIO25` | `/PRESENCE` | Radar Hardware Presence flag from RADAR1 (Pin 5) |
| **Pin 10** | `GPIO26` | `/FALL` | Radar Hardware Fall Detection flag from RADAR1 (Pin 6) |
| **Pin 11** | `GPIO27` | `/RADAR_EN` | Load Switch Gate Control $\rightarrow$ U6 DBVT Enable (Pin 3) |
| **Pin 12** | `GPIO14` | *Unconnected* | Floating |
| **Pin 13** | `GPIO12` | *Unconnected* | Floating |
| **Pin 14** | `GND` | `GND` | Common Ground Plane |
| **Pin 15** | `GPIO13` | `/PIR_WAKE` | Motion Wake Interrupt from ATtiny85 (P2 / Pin 4) |
| **Pin 16** | `VIN` | *Unconnected* | DevKit 5V input (bypassed via Pin 1 3V3) |
| **Pin 17** | `GND` | `GND` | Common Ground Plane |
| **Pin 18** | `GPIO23` | *Unconnected* | Floating |
| **Pin 19** | `GPIO22` | *Unconnected* | Floating |
| **Pin 20** | `TX0` | *Unconnected* | DevKit USB-UART bridge |
| **Pin 21** | `RX0` | *Unconnected* | DevKit USB-UART bridge |
| **Pin 22** | `GPIO21` | *Unconnected* | Floating |
| **Pin 23** | `GPIO19` | `Net-(U1-GPIO19)` | Fall Alarm Visual Siren LED driver $\rightarrow$ R3 (Pin 1) |
| **Pin 24** | `GPIO18` | *Unconnected* | Floating |
| **Pin 25** | `GPIO5` | *Unconnected* | Floating |
| **Pin 26** | `GPIO17` | `/RADAR_RX` | ESP32 UART RX $\leftarrow$ RADAR1 TX (Pin 3) |
| **Pin 27** | `GPIO16` | `/RADAR_TX` | ESP32 UART TX $\rightarrow$ RADAR1 RX (Pin 4) |
| **Pin 28** | `GPIO4` | `/MIC_WAKE` | Acoustic Thud Wake Interrupt from ATtiny85 (P0 / Pin 6) |
| **Pin 29** | `GPIO2` | *Unconnected* | Floating (DevKit onboard blue LED) |
| **Pin 30** | `GPIO15` | *Unconnected* | Floating |

---

### `U2` — Digispark ATtiny85 (Ultra-Low Power Wake Sentinel)
| Pin # | Pin Label | Connected Net | Destination / Function |
|---|---|---|---|
| **Pin 1** | `P5 / RESET` | *Unconnected* | Hardware Reset (internally pulled up) |
| **Pin 2** | `P4 (ADC2)` | `Net-(U2-P4)` | Acoustic Thud Input from LM393 `DO` (Pin 3) |
| **Pin 3** | `P3` | *Unconnected* | Floating |
| **Pin 4** | `P2 (SCK)` | `/PIR_WAKE` | 50ms Motion Wake pulse $\rightarrow$ ESP32 GPIO 13 |
| **Pin 5** | `P1 (MISO)` | `Net-(PIR1-OUT)` | Motion Signal Input from AM312 PIR (Pin 2) |
| **Pin 6** | `P0 (AREF)` | `/MIC_WAKE` | 50ms Acoustic Thud Wake pulse $\rightarrow$ ESP32 GPIO 4 |
| **Pin 7** | `GND` | `GND` | Common Ground Plane |
| **Pin 8** | `VIN` | *Unconnected* | Onboard regulator 5V input (bypassed) |
| **Pin 9** | `5V / VCC` | `+3V3` | Power Input ($< 1\text{ µA}$ deep sleep at 3.3V) |

---

## 3. 📡 Radar Detection Subsystem

### `U6` — DBVT SOT-23-6 Load Switch (Radar Power Gating)
| Pin # | Pin Name | Connected Net | Destination / Purpose |
|---|---|---|---|
| **Pin 1** | VIN | `+5V` | Always-on +5V rail from MT3608 Boost |
| **Pin 2** | GND | `GND` | Common Ground Plane |
| **Pin 3** | EN | `/RADAR_EN` | Active-High radar power gate from ESP32 GPIO 27 |
| **Pin 4** | GND | `GND` | Common Ground Plane |
| **Pin 5** | GND | `GND` | Common Ground Plane |
| **Pin 6** | VOUT | `Net-(RADAR1-VIN)` | Switched +5V power feed $\rightarrow$ RADAR1 VIN (Pin 1) |

---

### `RADAR1` — C1001 60GHz Millimeter-Wave Fall Detection Radar
| Pin # | Pin Name | Connected Net | Destination / Purpose |
|---|---|---|---|
| **Pin 1** | VIN | `Net-(RADAR1-VIN)` | Gated +5V power from U6 Load Switch (Pin 6) |
| **Pin 2** | GND | `GND` | Common Ground Plane |
| **Pin 3** | TX | `/RADAR_TX` | Radar Serial Data Out $\rightarrow$ ESP32 GPIO 16 (RX) |
| **Pin 4** | RX | `/RADAR_RX` | Radar Serial Data In $\leftarrow$ ESP32 GPIO 17 (TX) |
| **Pin 5** | OUT1 | `/PRESENCE` | GPIO Fast-Path Presence Flag $\rightarrow$ ESP32 GPIO 25 |
| **Pin 6** | OUT2 | `/FALL` | GPIO Fast-Path Dynamic Fall Flag $\rightarrow$ ESP32 GPIO 26 |

---

## 4. 👁️ Sentinel Sensors (PIR Motion & Acoustic Thud)

### `PIR1` — AM312 Low-Power PIR Motion Sensor
| Pin # | Pin Name | Connected Net | Destination / Purpose |
|---|---|---|---|
| **Pin 1** | VCC | `+3V3` | +3.3V Power Rail |
| **Pin 2** | OUT | `Net-(PIR1-OUT)` | Motion output signal $\rightarrow$ ATtiny85 Pin 5 (P1) |
| **Pin 3** | GND | `GND` | Common Ground Plane |

> [!NOTE]
> **Orientation:** Body is flipped horizontally towards the **RIGHT** ($X \in [124.0, 144.0]$) into the wide-open copper zone, completely clear of C4 and C8.

---

### `U5` — LM393 Sound / Acoustic Thud Sensor Module
| Pin # | Pin Name | Connected Net | Destination / Purpose |
|---|---|---|---|
| **Pin 1** | VCC | `+3V3` | +3.3V Power Rail |
| **Pin 2** | GND | `GND` | Common Ground Plane |
| **Pin 3** | DO | `Net-(U2-P4)` | Digital Thud Output $\rightarrow$ ATtiny85 Pin 2 (P4) |
| **Pin 4** | AO | *Unconnected* | Analog audio output (not used in digital wake design) |

---

## 5. 🎛️ User Interface & Peripherals

### `SW1` — Tactile Sync / Fall Disarm Push Button (4-Pin)
| Pin # | Connected Net | Destination / Purpose |
|---|---|---|
| **Pins 1 & 1** | `Net-(U1-GPIO33)` | Button switch contact $\rightarrow$ ESP32 GPIO 33 |
| **Pins 2 & 2** | `+3V3` | Pulled high to +3.3V on button press |

---

### `D1` — Fall Alarm Visual Siren LED (3mm Red)
| Pin # | Pin Name | Connected Net | Destination / Purpose |
|---|---|---|---|
| **Pin 1** | Anode (A) | `Net-(D1-A)` | Driven by R3 current limiting resistor |
| **Pin 2** | Cathode (K) | `GND` | Common Ground Plane |

---

## 6. ⚡ Resistors & Capacitors (THT 5-Capacitor Architecture)

| Component | Value | Package | Pin 1 Net | Pin 2 Net | Circuit Role |
|---|---|---|---|---|---|
| **`R1`** | 100kΩ | Axial 10.16mm | `Net-(U4-OUT+)` | `/BATT_ADC` | Battery Voltage Divider (Upper arm) |
| **`R2`** | 100kΩ | Axial 10.16mm | `/BATT_ADC` | `GND` | Battery Voltage Divider (Lower arm $\rightarrow$ 50% ratio) |
| **`R3`** | 270Ω | Axial 10.16mm | `Net-(U1-GPIO19)` | `Net-(D1-A)` | Current Limiting Resistor for Alarm LED D1 |
| **`C1`** | 10µF | Disc THT 5.0mm | `Net-(U4-OUT+)` | `GND` | Boost Input Stabilization (smooths battery voltage into MT3608) |
| **`C3`** | 470µF | Radial THT 5.0mm | `+5V` | `GND` | Main Water Tower Bulk Capacitor (absorbs Wi-Fi current spikes) |
| **`C4`** | 22µF | Radial THT 5.0mm | `+5V` | `GND` | Boost Output Filter (smooths 1.2MHz switching ripple) |
| **`C7`** | 0.1µF | Disc THT 5.0mm | `+3V3` | `GND` | ATtiny85 High-Frequency Decoupling |
| **`C8`** | 0.1µF | Disc THT 5.0mm | `+3V3` | `GND` | LM393 Sound Sensor High-Frequency Decoupling |

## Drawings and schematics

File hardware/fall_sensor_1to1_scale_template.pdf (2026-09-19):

## FALL SENSOR - 1:1 TRUE-SCALE CARRIER PCB TEMPLATE (TOP & BOTTOM)

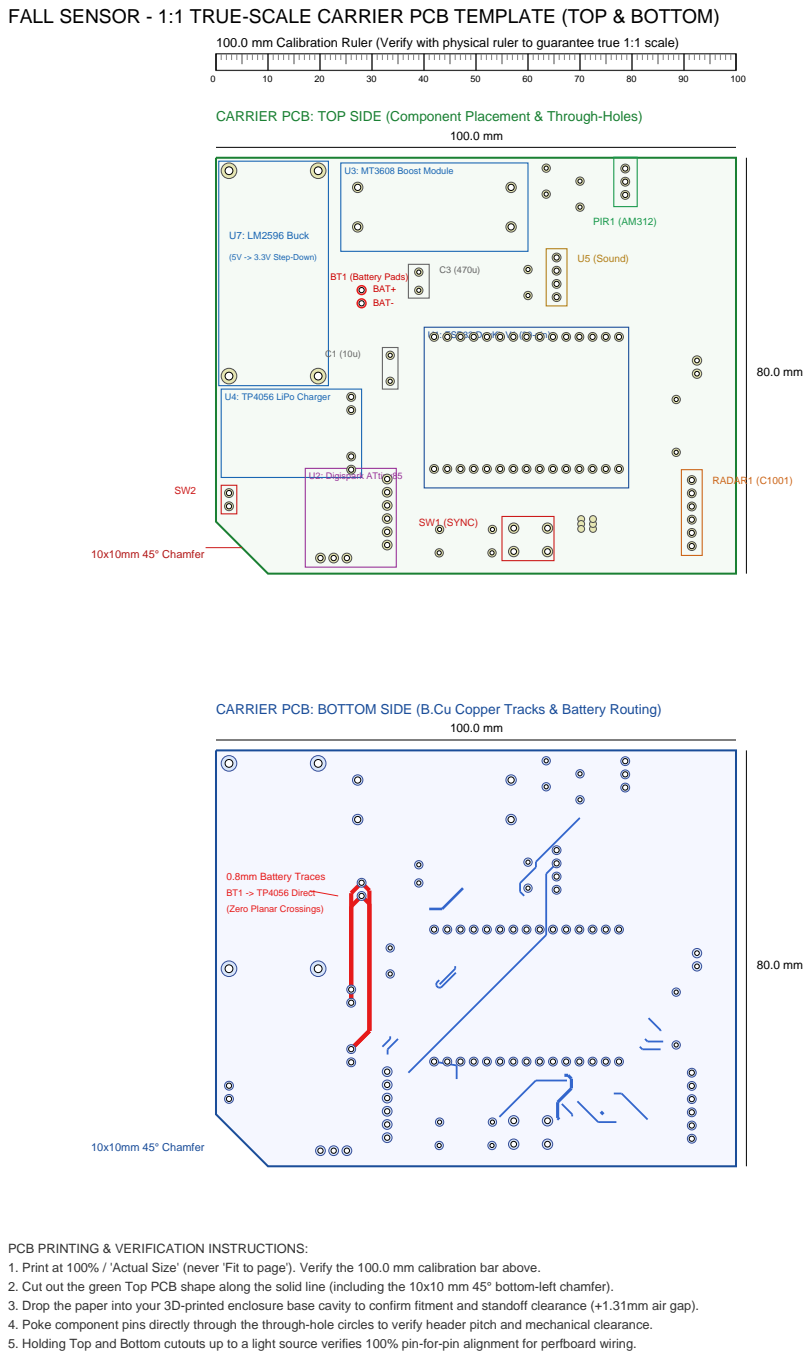
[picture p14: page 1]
10x10mm 45° Chamfer; U7: LM2596 Buck; (5V -> 3.3V Step-Down); U3: MT3608 Boost Module; U4: TP4056 LiPo Charger; U2: Digispark ATtiny85; U1: ESP32 DevKit V1 (30-pin); RADAR1 (C1001); PIR1 (AM312); U5 (Sound); SW1 (SYNC); C3 (470u) BT1 (Battery Pads); BAT+ BAT-

100.0 mm Calibration Ruler (Verify with physical ruler to guarantee true 1:1 scale)

CARRIER PCB: TOP SIDE (Component Placement & Through-Holes)

CARRIER PCB: BOTTOM SIDE (B.Cu Copper Tracks & Battery Routing)

0.8mm Battery Traces
BT1 -> TP4056 Direct
(Zero Planar Crossings)

PCB PRINTING & VERIFICATION INSTRUCTIONS:
1. Print at 100% / 'Actual Size' (never 'Fit to page'). Verify the 100.0 mm calibration bar above.
2. Cut out the green Top PCB shape along the solid line (including the 10x10 mm 45° bottom-left chamfer).
3. Drop the paper into your 3D-printed enclosure base cavity to confirm fitment and standoff clearance (+1.31mm air gap).
4. Poke component pins directly through the through-hole circles to verify header pitch and mechanical clearance.
5. Holding Top and Bottom cutouts up to a light source verifies 100% pin-for-pin alignment for perfboard wiring.

## FALL SENSOR - 1:1 ENCLOSURE BASE & LID TEMPLATE

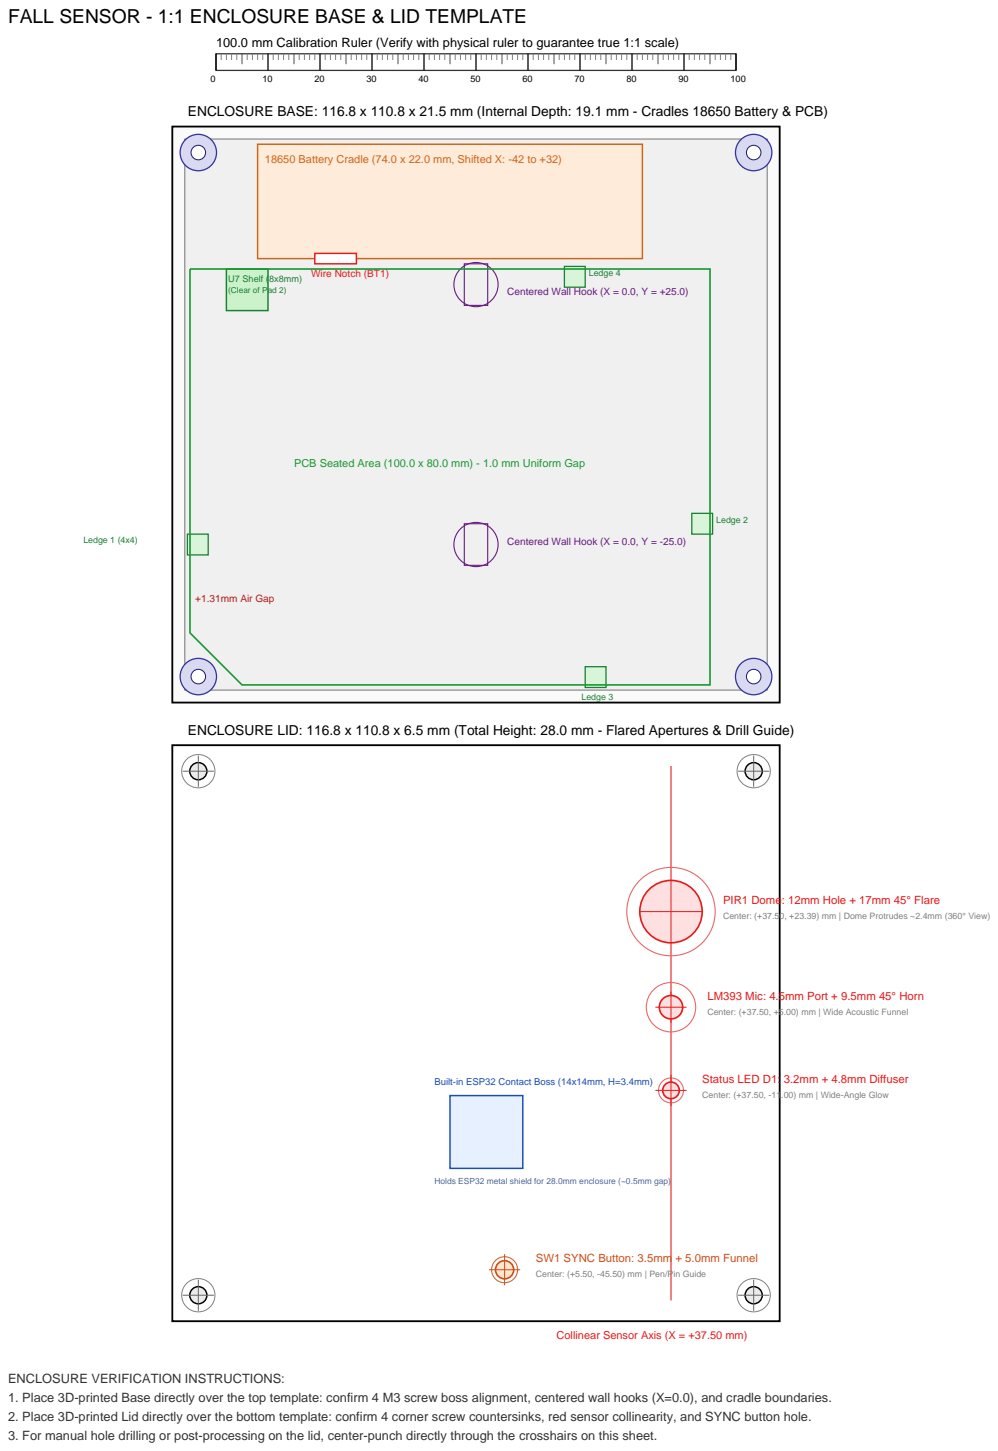
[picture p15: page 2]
Ledge 1 (4x4); Ledge 2; Ledge 3; Wire Notch (BT1); Ledge 4; +1.31mm Air Gap

100.0 mm Calibration Ruler (Verify with physical ruler to guarantee true 1:1 scale)

ENCLOSURE BASE: 116.8 x 110.8 x 21.5 mm (Internal Depth: 19.1 mm - Cradles 18650 Battery & PCB)

18650 Battery Cradle (74.0 x 22.0 mm, Shifted X: -42 to +32)

U7 Shelf (8x8mm)
(Clear of Pad 2)

Centered Wall Hook (X = 0.0, Y = +25.0)

PCB Seated Area (100.0 x 80.0 mm) - 1.0 mm Uniform Gap

Centered Wall Hook (X = 0.0, Y = -25.0)

ENCLOSURE LID: 116.8 x 110.8 x 6.5 mm (Total Height: 28.0 mm - Flared Apertures & Drill Guide)

PIR1 Dome: 12mm Hole + 17mm 45° Flare
Center: (+37.50, +23.39) mm | Dome Protrudes ~2.4mm (360° View)

LM393 Mic: 4.5mm Port + 9.5mm 45° Horn
Center: (+37.50, +5.00) mm | Wide Acoustic Funnel

Status LED D1: 3.2mm + 4.8mm Diffuser
Center: (+37.50, -11.00) mm | Wide-Angle Glow

Built-in ESP32 Contact Boss (14x14mm, H=3.4mm)

Holds ESP32 metal shield for 28.0mm enclosure (~0.5mm gap)

SW1 SYNC Button: 3.5mm + 5.0mm Funnel
Center: (+5.50, -45.50) mm | Pen/Pin Guide

Collinear Sensor Axis (X = +37.50 mm)

ENCLOSURE VERIFICATION INSTRUCTIONS:
1. Place 3D-printed Base directly over the top template: confirm 4 M3 screw boss alignment, centered wall hooks (X=0.0), and cradle boundaries.
2. Place 3D-printed Lid directly over the bottom template: confirm 4 corner screw countersinks, red sensor collinearity, and SYNC button hole.
3. For manual hole drilling or post-processing on the lid, center-punch directly through the crosshairs on this sheet.

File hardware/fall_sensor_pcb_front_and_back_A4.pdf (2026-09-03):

## FALL SENSOR PCB - 1:1 TRUE CAD SCALE PRINT SHEET (A4 LANDSCAPE)

### TOP LAYER (Components & F.SilkS)

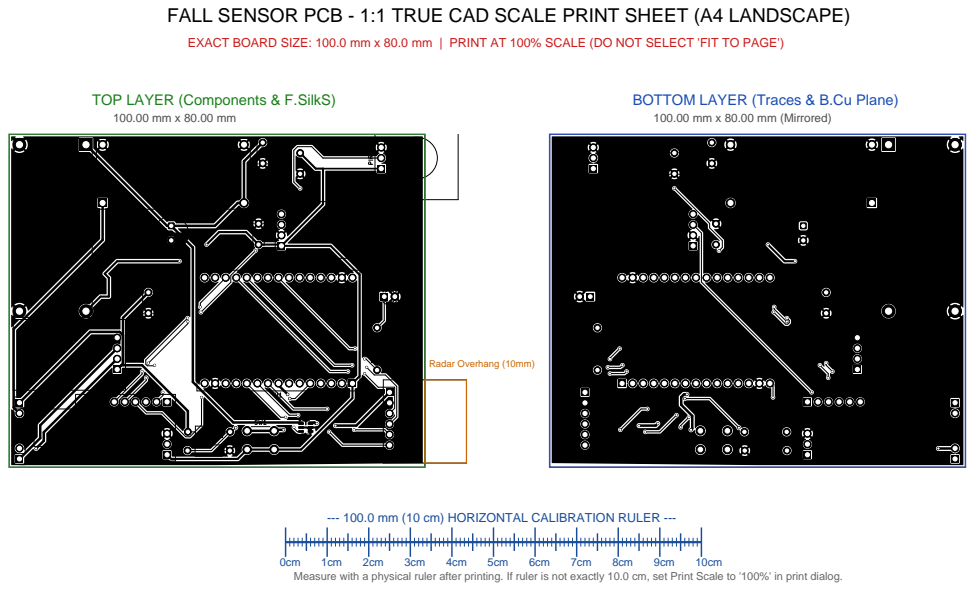
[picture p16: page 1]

EXACT BOARD SIZE: 100.0 mm x 80.0 mm | PRINT AT 100% SCALE (DO NOT SELECT 'FIT TO PAGE')

BOTTOM LAYER (Traces & B.Cu Plane)
100.00 mm x 80.00 mm (Mirrored)

--- 100.0 mm (10 cm) HORIZONTAL CALIBRATION RULER ---

Measure with a physical ruler after printing. If ruler is not exactly 10.0 cm, set Print Scale to '100%' in print dialog.

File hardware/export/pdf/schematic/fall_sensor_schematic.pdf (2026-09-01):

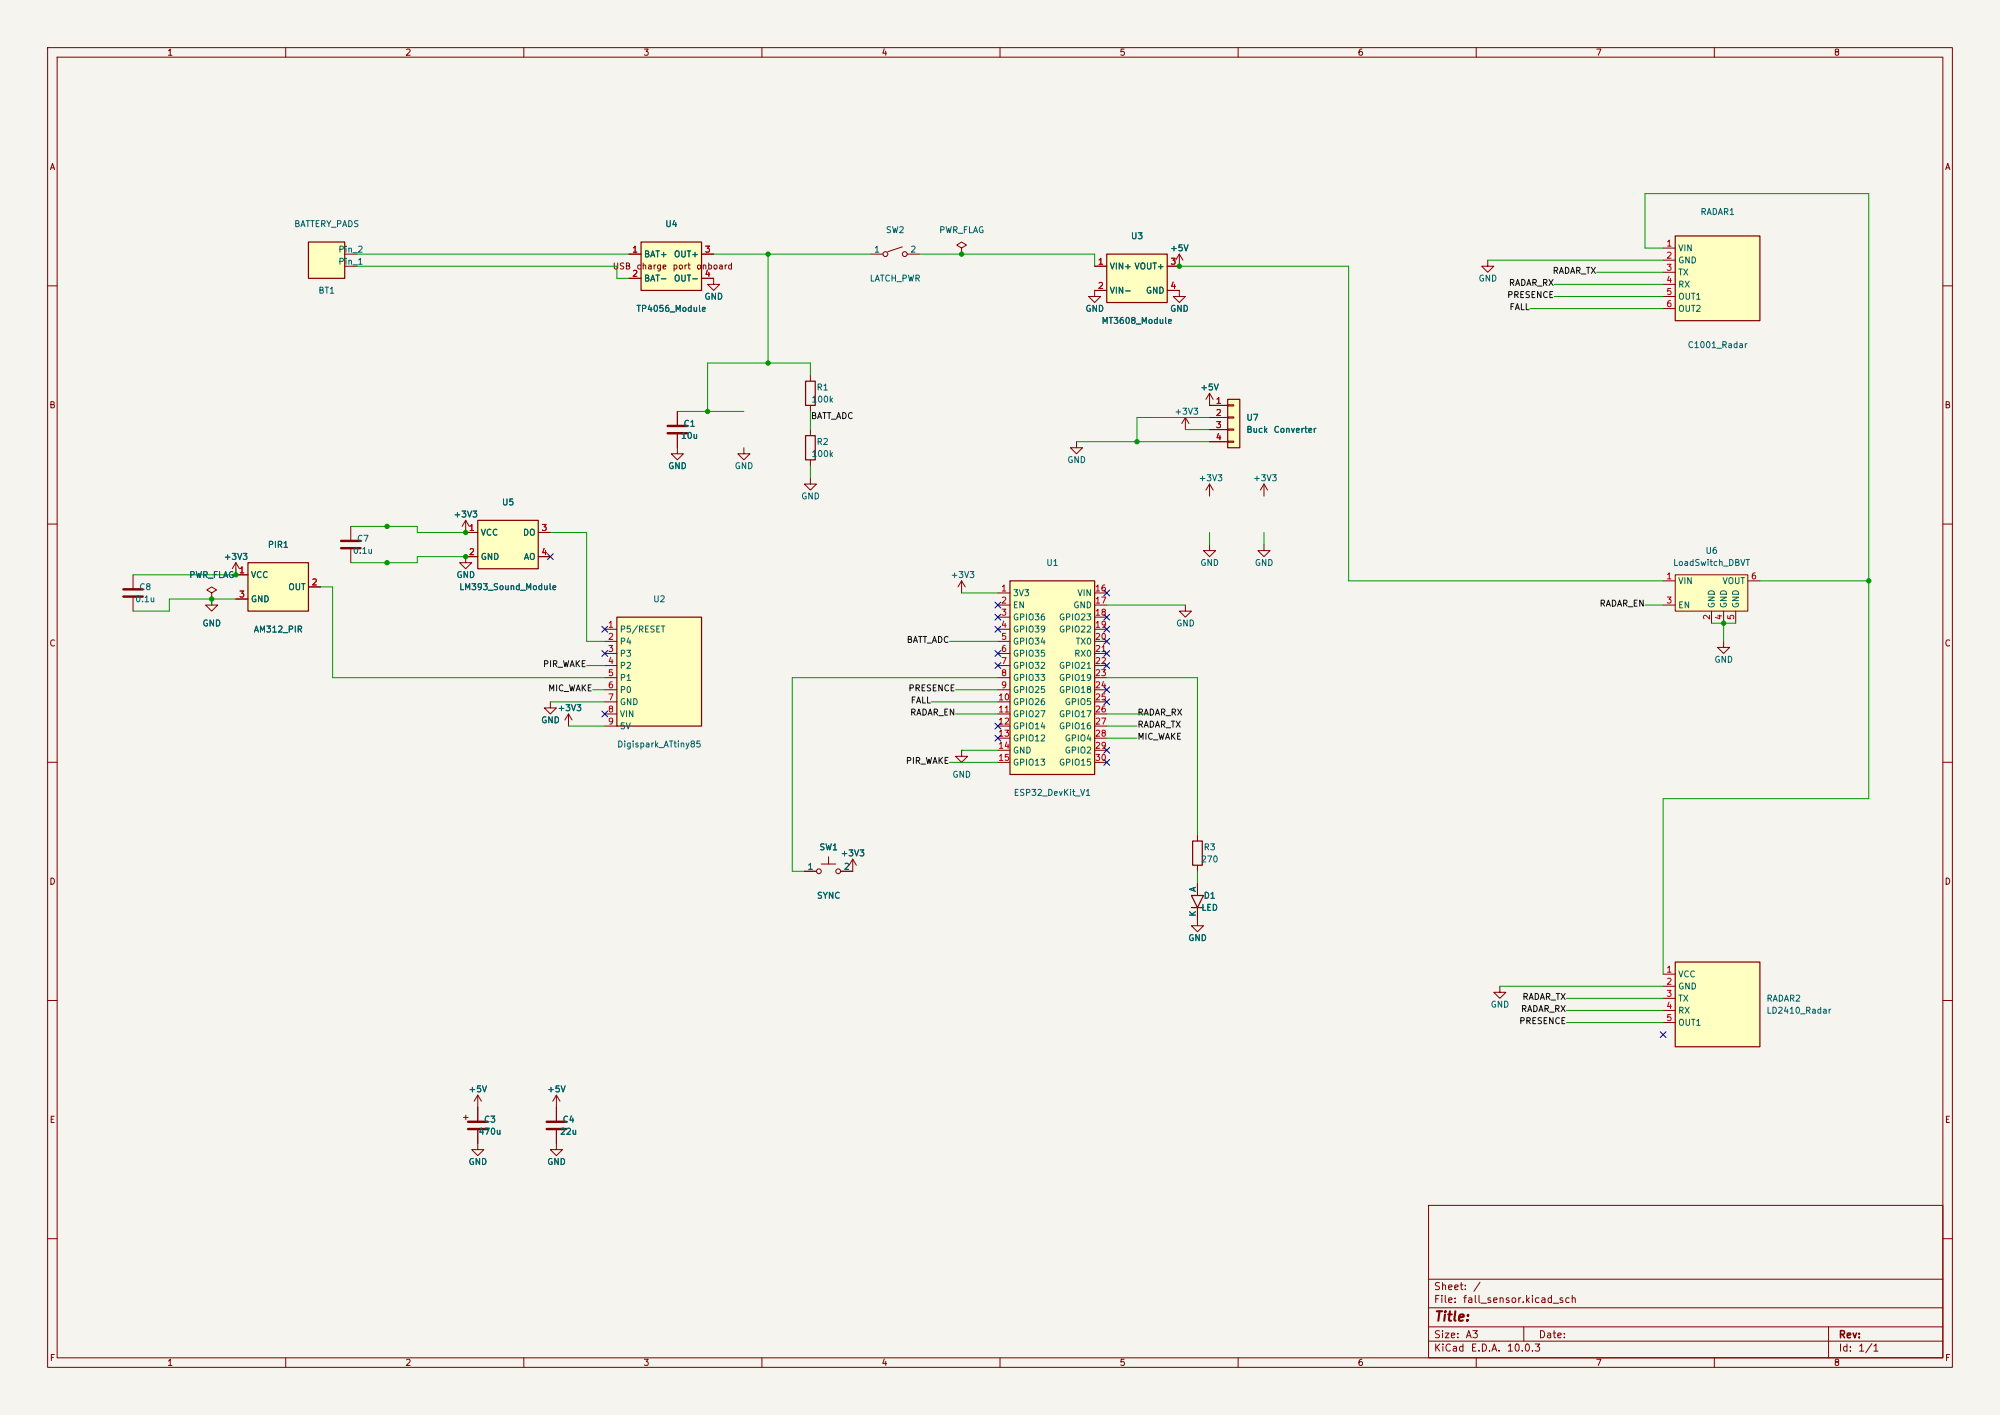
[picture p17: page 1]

Size: A3 | Rev: | F Date:
KiCad E.D.A. 10.0.3 | Id: 1/1

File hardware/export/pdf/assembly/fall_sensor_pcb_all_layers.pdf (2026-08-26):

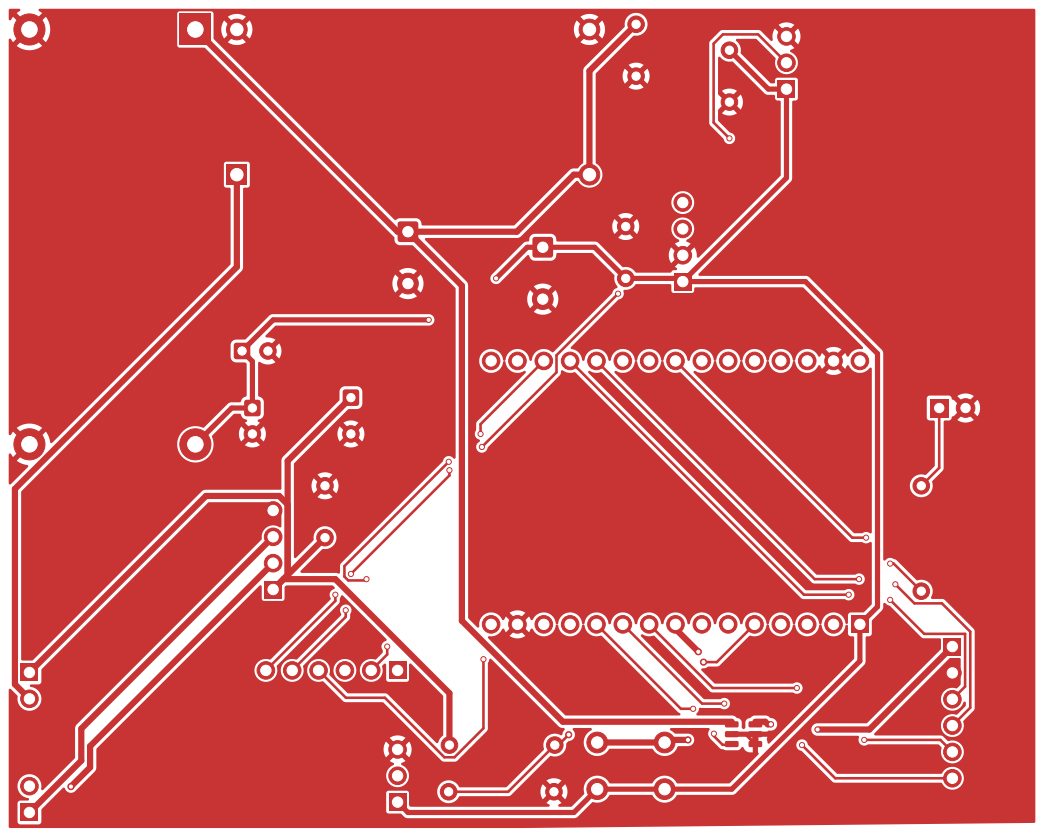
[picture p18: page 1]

Size: A4 | Rev:
KiCad E.D.A. 10.0.3 | Id: 1/7

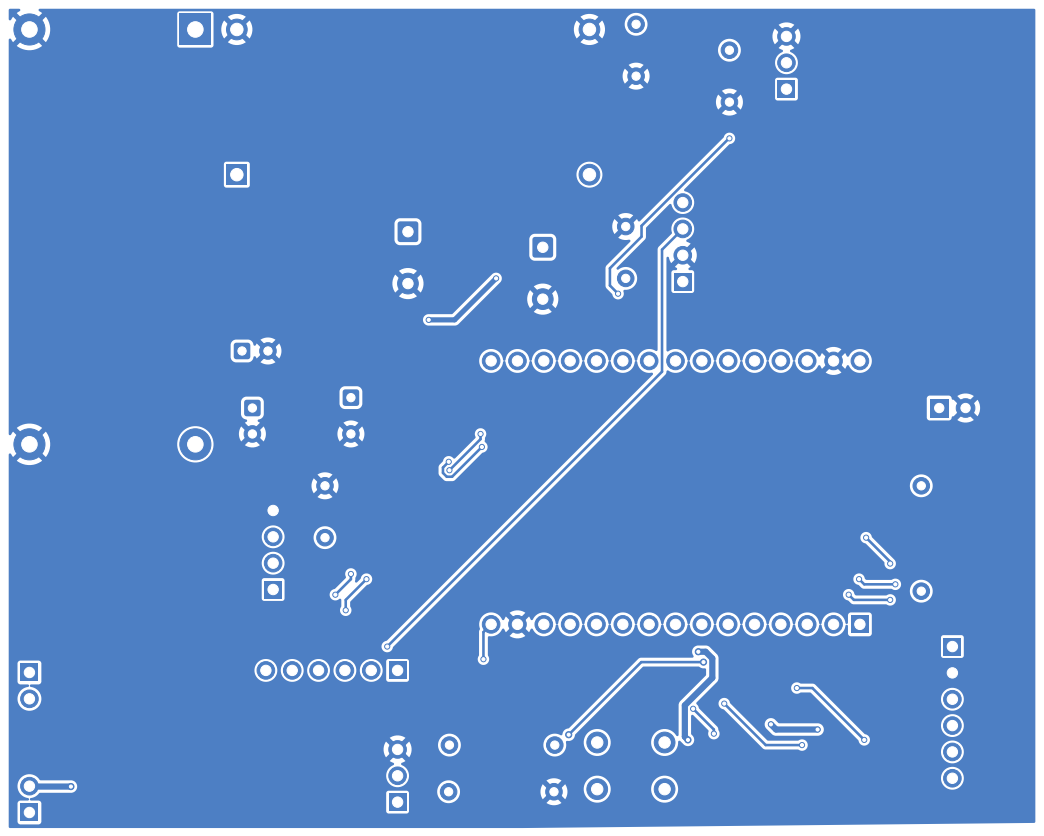
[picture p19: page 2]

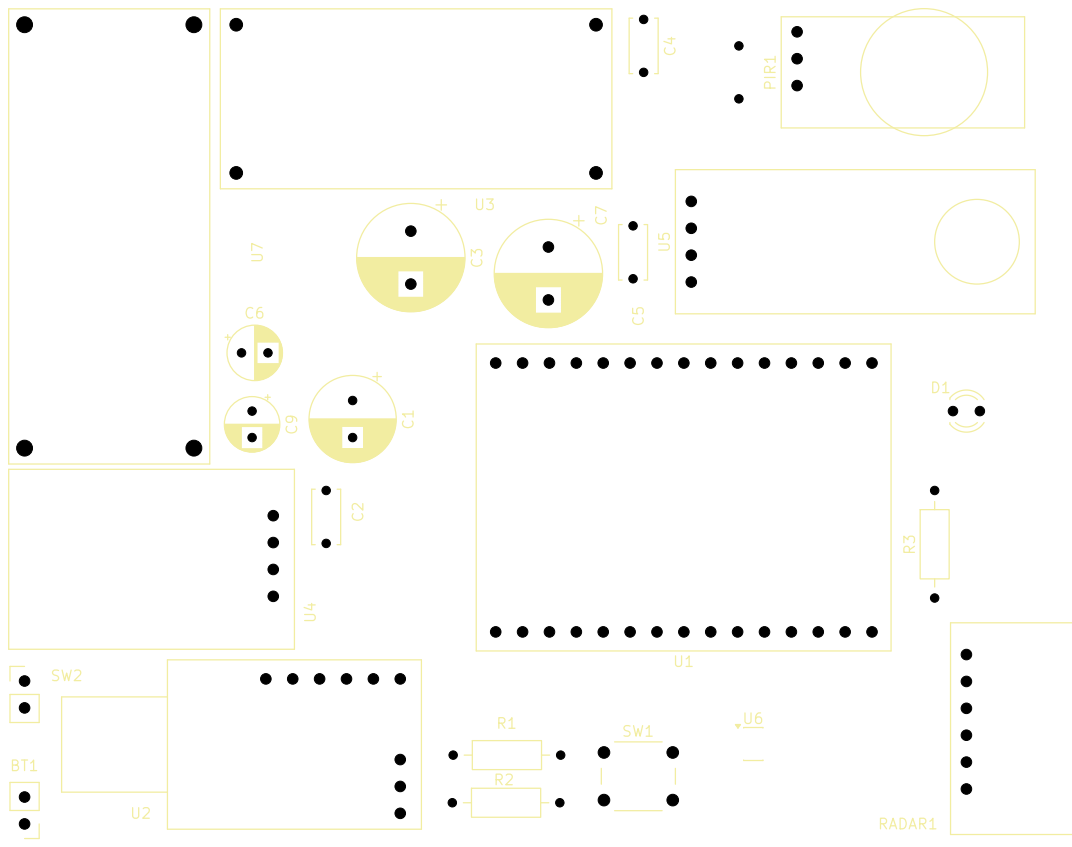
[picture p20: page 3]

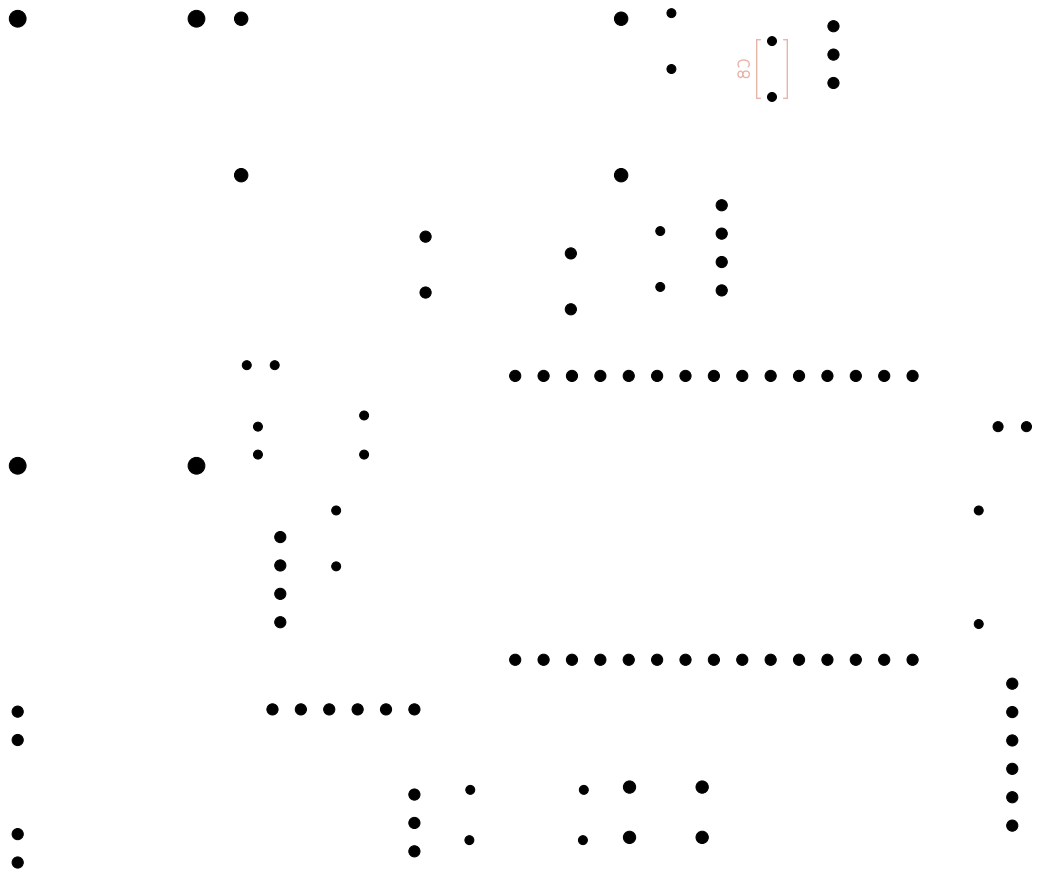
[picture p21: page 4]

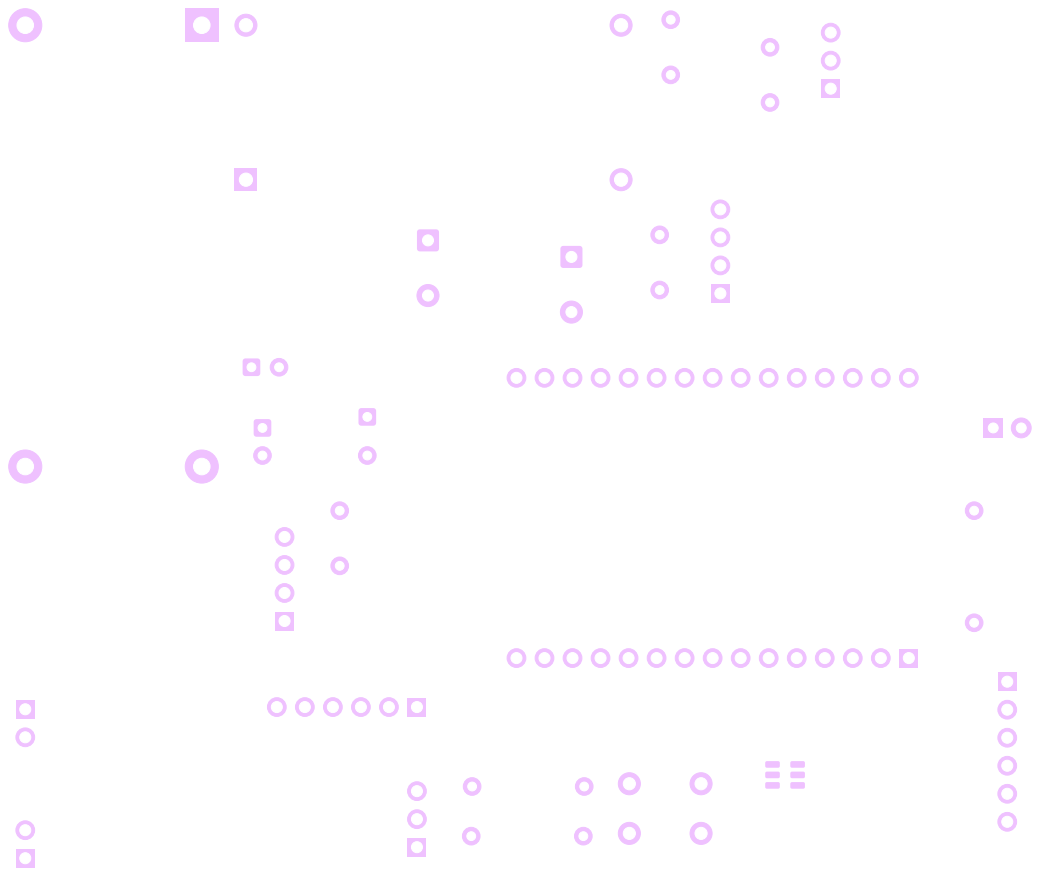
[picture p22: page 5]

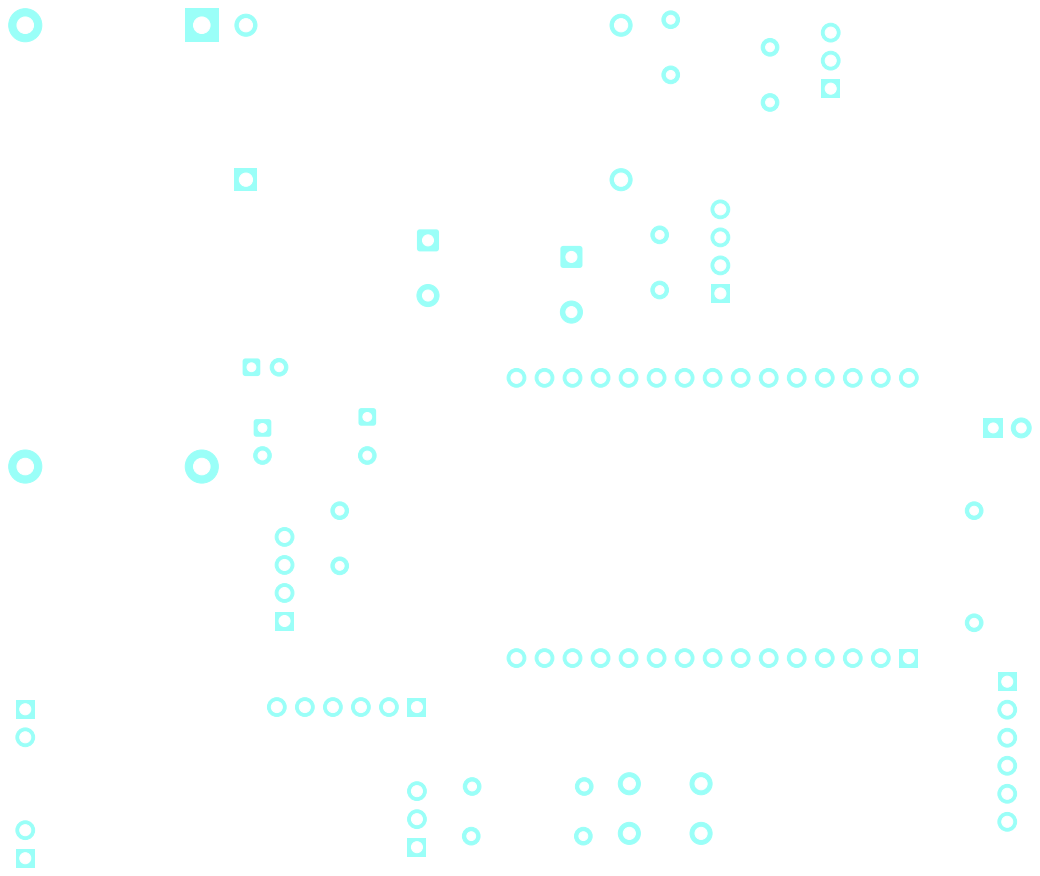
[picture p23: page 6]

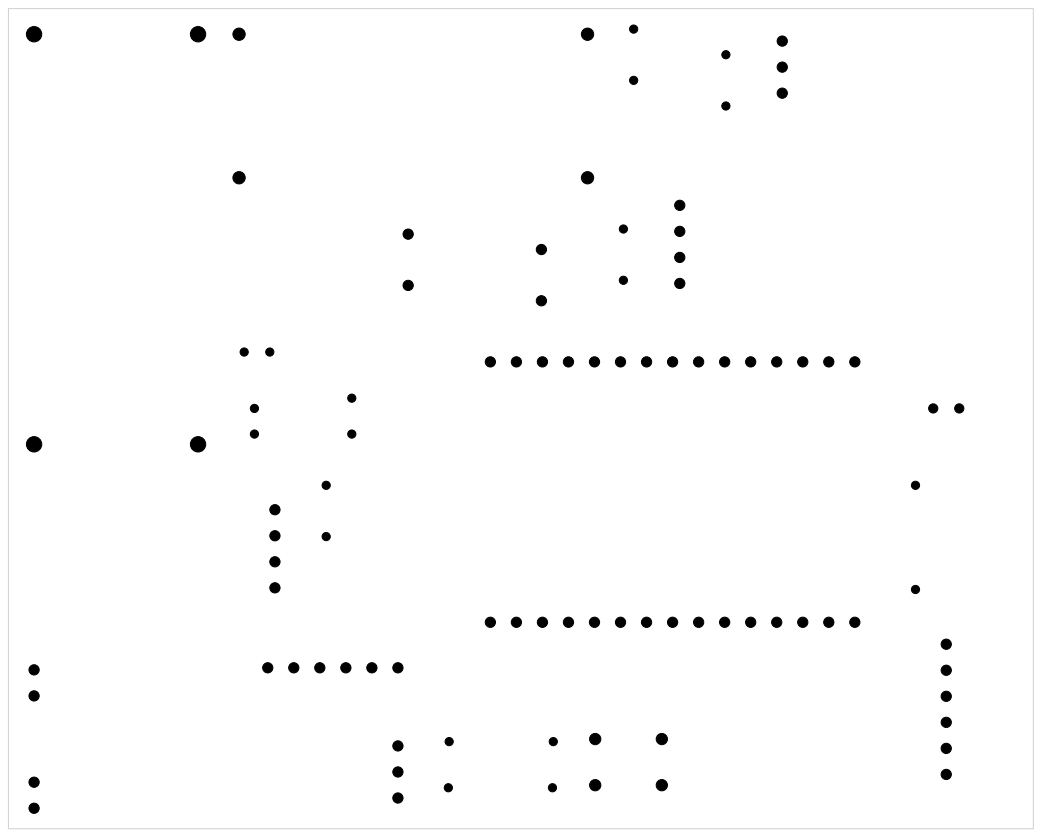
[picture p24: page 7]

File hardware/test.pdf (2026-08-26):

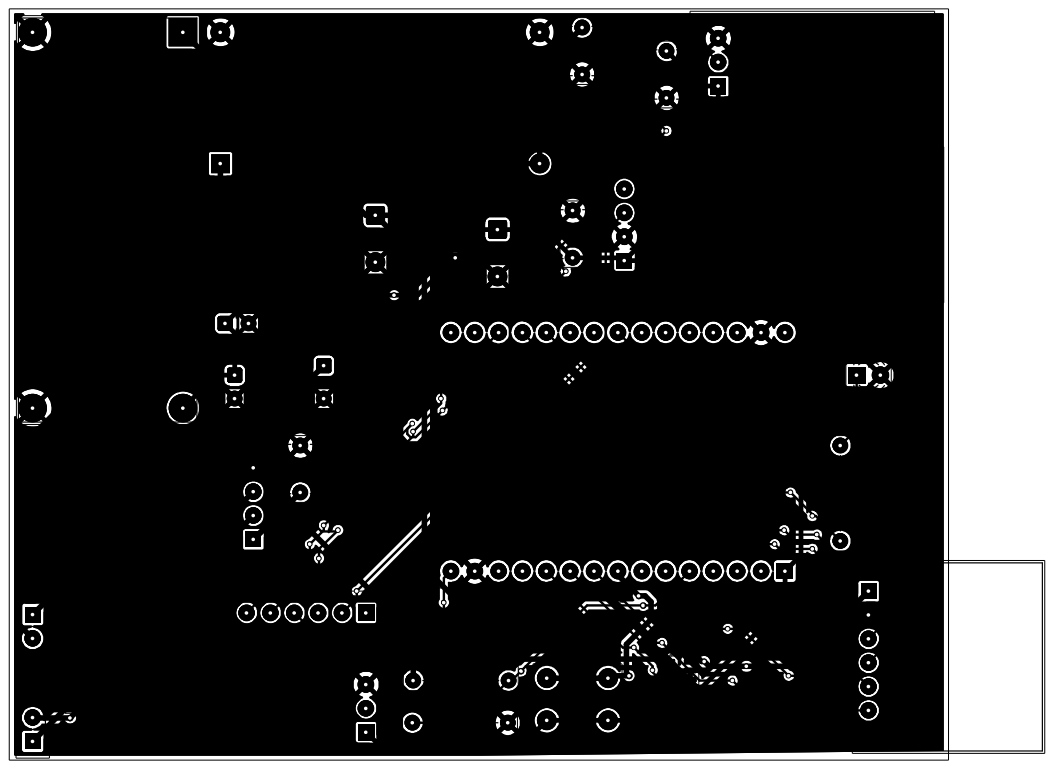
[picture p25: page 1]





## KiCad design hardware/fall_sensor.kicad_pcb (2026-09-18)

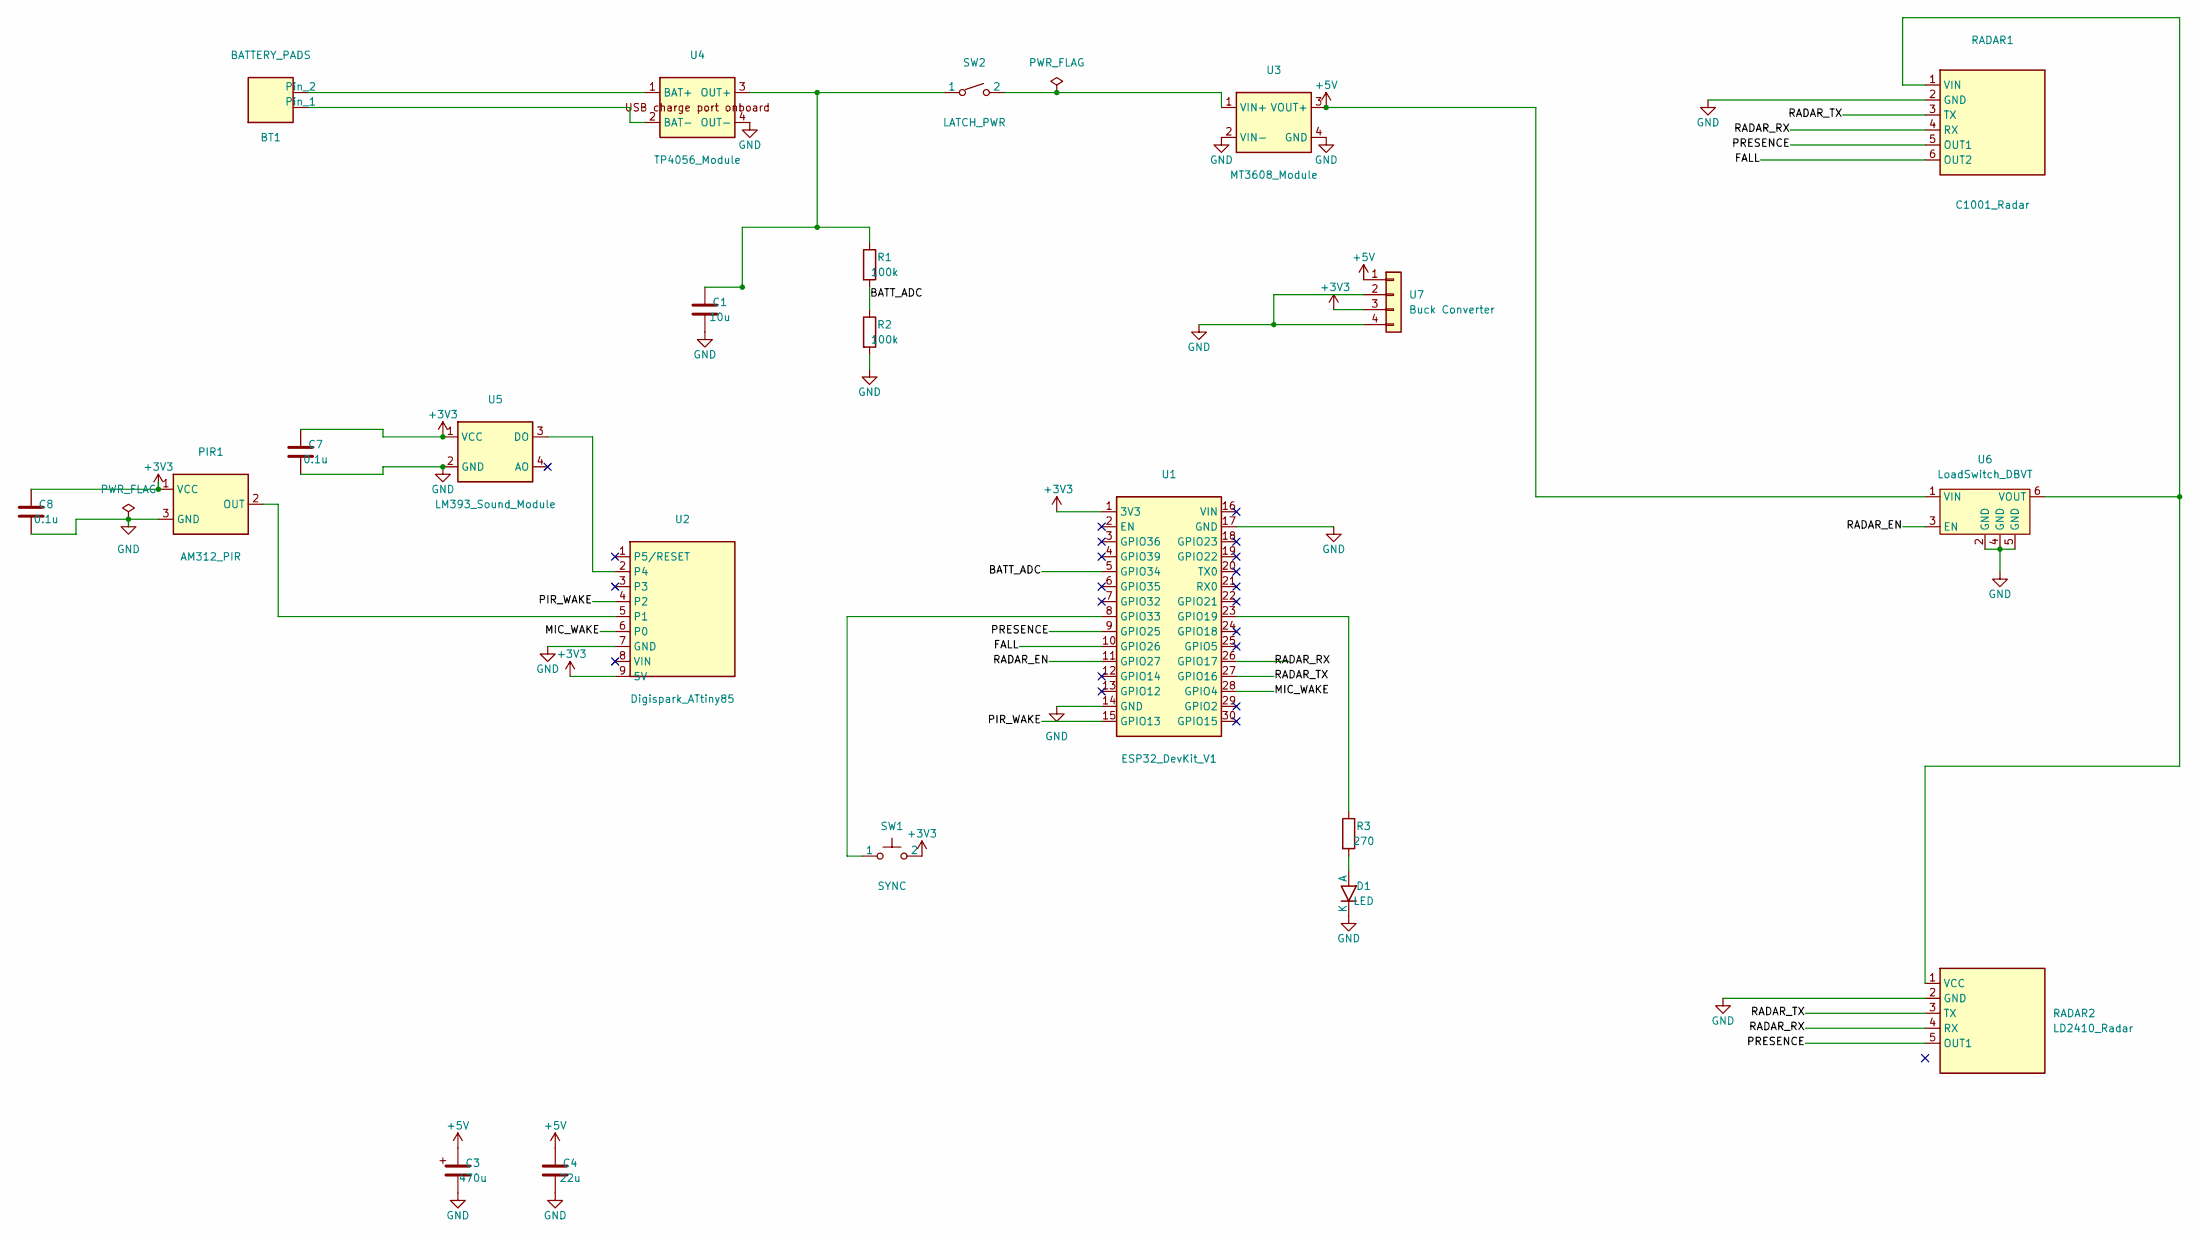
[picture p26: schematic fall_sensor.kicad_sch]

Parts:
BT1: BATTERY_PADS; PinHeader_1x02_P2.54mm_Vertical
C1: 10u; C_Disc_D5.0mm_W2.5mm_P5.00mm
C3: 470u; CP_Radial_D8.0mm_P3.50mm
C4: 22u; C_Disc_D5.0mm_W2.5mm_P5.00mm
C7, C8: 0.1u; C_Disc_D5.0mm_W2.5mm_P5.00mm
D1: LED; LED_D3.0mm
PIR1: AM312_PIR; AM312_PIR_Square22x20
R1, R2: 100k; R_Axial_DIN0207_L6.3mm_D2.5mm_P10.16mm_Horizontal
R3: 270; R_Axial_DIN0207_L6.3mm_D2.5mm_P10.16mm_Horizontal
RADAR1: C1001_Radar; C1001_Module
RADAR2: LD2410_Radar; LD2410_1.27mm
SW1: SYNC; SW_PUSH_6mm
SW2: LATCH_PWR; PinHeader_1x02_P2.54mm_Vertical
U1: ESP32_DevKit_V1; ESP32_DevKit_DOIT_2x15
U2: Digispark_ATtiny85; Digispark_9Pin_RightAngle
U3: MT3608_Module
U4: TP4056_Module
U5: LM393_Sound_Module
U6: LoadSwitch_DBVT; DIP-6_W7.62mm
U7: Buck Converter; LM2596_Module

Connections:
+3V3: C7.1, C8.1, PIR1.1 (VCC), SW1.2, U1.1 (3V3), U2.9 (5V), U5.1 (VCC), U7.3
+5V: C3.1, C4.1, U3.3 (VOUT+), U6.1 (VIN), U7.1
/BATT_ADC: R1.2, R2.1, U1.5 (GPIO34)
/FALL: RADAR1.6 (OUT2), U1.10 (GPIO26)
/MIC_WAKE: U1.28 (GPIO4), U2.6 (P0)
/PIR_WAKE: U1.15 (GPIO13), U2.4 (P2)
/PRESENCE: RADAR1.5 (OUT1), RADAR2.5 (OUT1), U1.9 (GPIO25)
/RADAR_EN: U1.11 (GPIO27), U6.3 (EN)
/RADAR_RX: RADAR1.4 (RX), RADAR2.4 (RX), U1.26 (GPIO17)
/RADAR_TX: RADAR1.3 (TX), RADAR2.3 (TX), U1.27 (GPIO16)
GND: C1.2, C3.2, C4.2, C7.2, C8.2, D1.2 (K), PIR1.3 (GND), R2.2, RADAR1.2 (GND), RADAR2.2 (GND), U1.14 (GND), U1.17 (GND), U2.7 (GND), U3.2 (VIN-), U3.4 (GND), U4.4 (OUT-), U5.2 (GND), U6.2 (GND), U6.4 (GND), U6.5 (GND), U7.2, U7.4
unnamed: BT1.1, U4.2 (BAT-)
unnamed: BT1.2, U4.1 (BAT+)
unnamed: D1.1 (A), R3.2
unnamed: PIR1.2 (OUT), U2.5 (P1)
unnamed: RADAR1.1 (VIN), RADAR2.1 (VCC), U6.6 (VOUT)
unnamed: R3.1, U1.23 (GPIO19)
unnamed: SW1.1, U1.8 (GPIO33)
unnamed: U2.2 (P4), U5.3 (DO)
unnamed: SW2.2, U3.1 (VIN+)
unnamed: C1.1, R1.1, SW2.1, U4.3 (OUT+)

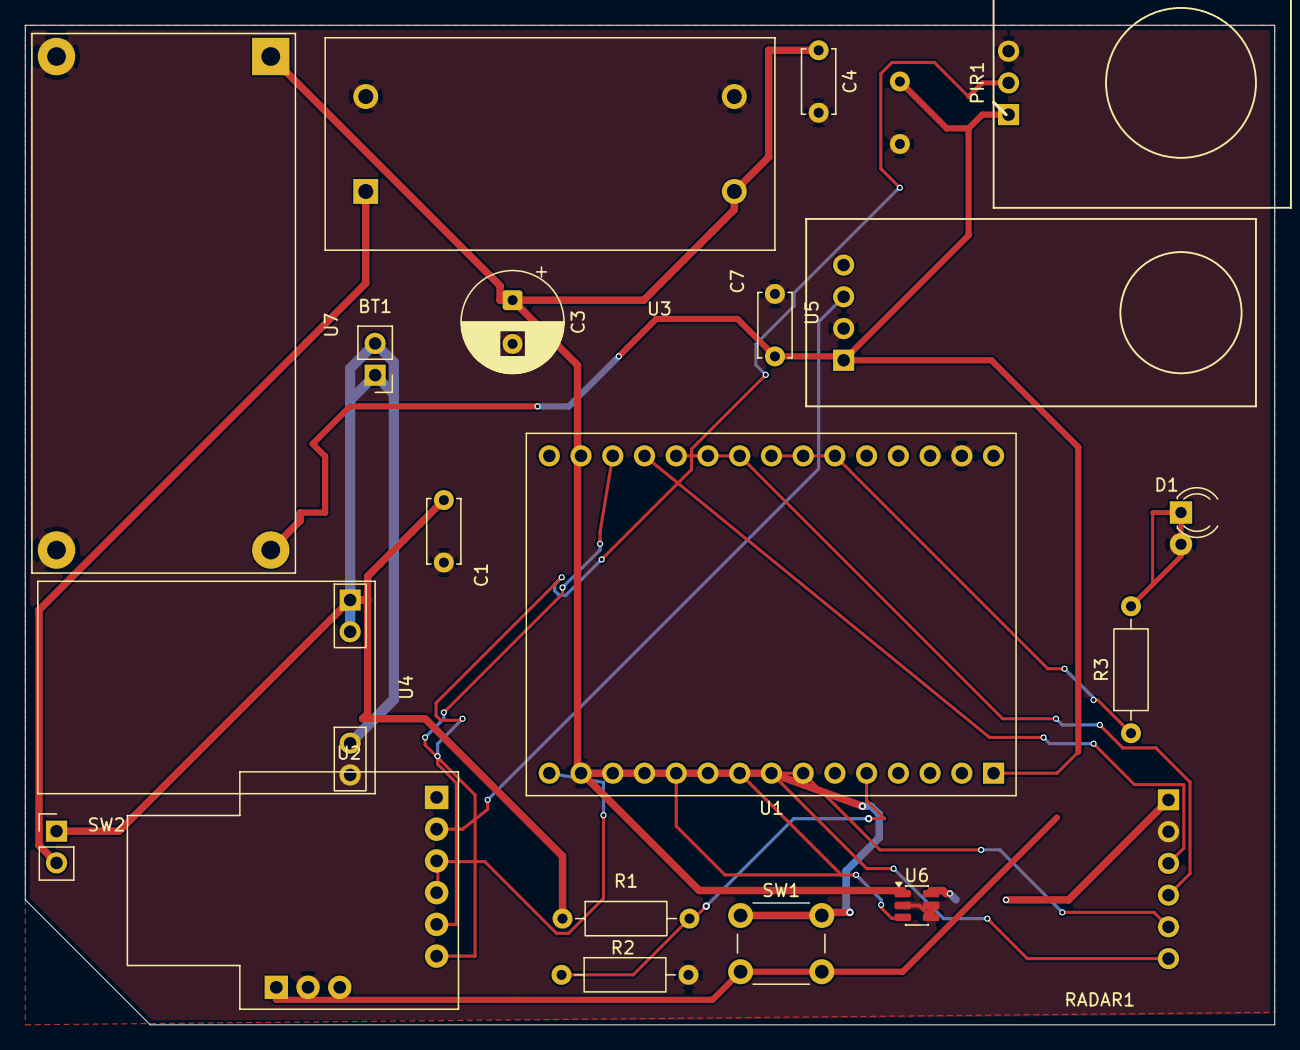
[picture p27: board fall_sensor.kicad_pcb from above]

Board: 2 copper layers, 100.0 x 80.0 mm, 21 parts (1 on the bottom side), 21 nets.

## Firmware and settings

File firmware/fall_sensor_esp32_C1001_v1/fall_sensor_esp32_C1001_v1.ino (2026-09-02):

// VERSION: v4.23 - Gradual Posture Collapse Detection (Silent Fall Fix) (2026-09-02)

#include <WiFi.h>
#include <ArduinoOTA.h>
#include <BLEDevice.h>
#include <BLEServer.h>
#include <BLEUtils.h>
#include <BLE2902.h>
#include <DFRobot_HumanDetection.h>
#include <driver/rtc_io.h>

// --- USER CONFIGURABLE CEILING & ROOM HEIGHT SETTINGS ---
// Default: 9 feet = 274 cm (persists across deep sleep cycles in RTC memory)
RTC_DATA_ATTR int roomHeightCm = 274;         
RTC_DATA_ATTR int floorToleranceCm = 45;      // Target detected between (roomHeight - 45) and (roomHeight + 35) is at floor level
RTC_DATA_ATTR int floorLyingConsecutiveChecks = 0; // Number of consecutive periodic checks target remains on floor
const int FLOOR_LYING_ALERT_THRESHOLD = 2;   // 2 consecutive checks (~60-120s) triggers static fall alarm
RTC_DATA_ATTR int lastStandingDistCm = 0;          // Last distance when person was in standing zone
RTC_DATA_ATTR unsigned long lastStandingTime = 0;   // millis() when last seen standing

// --- HARDWARE PINS ---
#define PIR_WAKE_PIN     13  
#define MIC_WAKE_PIN     4   
#define PRESENCE_PIN     25  // C1001 OUT1
#define FALL_PIN         26  // C1001 OUT2
#define SYNC_BUTTON_PIN  33  
#define BATTERY_PIN      34  
#define RADAR_MOSFET_PIN 27  
#define FALL_LED_PIN     19  
#define RX_PIN           16  
#define TX_PIN           17  

// --- BLE UUIDS ---
#define SERVICE_UUID           "4fafc201-1fb5-459e-8fcc-c5c9c331914b"
#define CHARACTERISTIC_UUID    "beb5483e-36e1-4688-b7f5-ea07361b26a8"

BLEServer* pServer = NULL;
BLECharacteristic* pCharacteristic = NULL;
bool deviceConnected = false;
bool isBleAdvertising = false;
unsigned long bleTurnedOnTime = 0;
bool debugMode = false;

// --- STATE & TIMERS ---
RTC_DATA_ATTR int bootCount = 0;
RTC_DATA_ATTR bool wasOccupied = false; // Remembers occupancy across deep sleep
unsigned long lastPirLogTime = 0;
unsigned long lastMicLogTime = 0;
RTC_DATA_ATTR int occupiedCount = 0;  // consecutive occupied snapshots for sleep backoff

enum TriggerSource { BOOT, PIR_WALK_IN, MIC_THUD, MANUAL_SYNC, PERIODIC_TIMER };
TriggerSource currentTrigger = BOOT;

uint64_t PERIODIC_SLEEP_SEC = 60; // Configurable periodic sleep

bool isRadarPowered = false;
unsigned long radarTurnedOnTime = 0;
unsigned long lastLedFlash = 0;
unsigned long lastDebugLog = 0;

// Smart logging: track last values to only log on change or 10s heartbeat
bool lastLoggedHWPres = false;
bool lastLoggedUARTPres = false;
bool lastLoggedHWFall = false;
bool lastLoggedUARTFall = false;
uint16_t lastLoggedDist = 0;
unsigned long lastHeartbeatLog = 0;
const unsigned long HEARTBEAT_LOG_INTERVAL = 10000;  // 10 seconds

bool fallConfirmed = false;
unsigned long sustainedMoveStartTime = 0;
bool batteryReported = false;
bool batteryCritical = false;

volatile bool syncButtonPressed = false;
volatile bool pirTriggered = false;
volatile bool micTriggered = false;
bool requestRadarPowerOn = false;

// Sensor Fusion Tracking
bool pirSeenInSnapshot = false;
bool micSeenInSnapshot = false;

// Fake Sleep (When BLE is connected)
bool isFakeSleeping = false;
bool infiniteFakeSleep = false;
unsigned long fakeSleepStartTime = 0;

const unsigned long DEBOUNCE_COOLDOWN = 3000;
unsigned long lastSleepTime = 0;  // PIR cooldown: ignore PIR for 5s after sleeping
const unsigned long PIR_COOLDOWN_MS = 5000;

#define WIFI_SSID "Jio-ruby105"
#define WIFI_PASS "Pumba@6969"
bool otaActive = false;
unsigned long otaStartTime = 0;
bool requestOtaStart = false;
bool otaConnecting = false;
unsigned long otaConnectStartTime = 0;
bool otaDisconnectBlePending = false;
unsigned long otaDisconnectBleTime = 0;

HardwareSerial RadarSerial(1);
DFRobot_HumanDetection hu(&RadarSerial);

void startBLE();
void stopBLE();
void powerOnRadar();
void goToSleep(bool infinite);

class MyServerCallbacks: public BLEServerCallbacks {
    void onConnect(BLEServer* pServer) {
      deviceConnected = true;
      isBleAdvertising = false;
      batteryReported = false; 
      bleTurnedOnTime = millis();
    }
    void onDisconnect(BLEServer* pServer) {
      deviceConnected = false;
      isFakeSleeping = false;
      // Auto LOG_OFF: stop wasting resources logging to nobody
      if (debugMode) {
          debugMode = false;
      }
      // Auto OTA_OFF: don't leave WiFi running with no controller
      if (otaActive) {
          otaActive = false;
          WiFi.disconnect(true);
          WiFi.mode(WIFI_OFF);
      }
      // If we disconnect while fake sleeping, immediately real sleep
      if (!isRadarPowered) goToSleep(infiniteFakeSleep);
    }
};

void IRAM_ATTR syncButtonISR() { syncButtonPressed = true; }
void IRAM_ATTR pirISR() { pirTriggered = true; }
void IRAM_ATTR micISR() { micTriggered = true; }

class MyCallbacks: public BLECharacteristicCallbacks {
    void onWrite(BLECharacteristic *pChar) {
      String rxValue = pChar->getValue(); 
      if (rxValue.length() > 0) {
        if (rxValue.indexOf("LOG_ON") != -1) {
          if (debugMode) {
              pChar->setValue("Debug Mode: Already ON. Ignoring.\n");
              pChar->notify();
          } else {
              debugMode = true;
              pChar->setValue("Debug Mode: ENABLED\n");
              pChar->notify();
              requestRadarPowerOn = true;
          }
        }
        else if (rxValue.indexOf("LOG_OFF") != -1) {
          debugMode = false;
          pChar->setValue("Debug Mode: DISABLED\n");
          pChar->notify();
        }
        else if (rxValue.startsWith("SET:HEIGHT:")) {
          int newH = rxValue.substring(11).toInt();
          if (newH >= 150 && newH <= 500) {
              roomHeightCm = newH;
              String reply = "[CFG] Room Height set to " + String(roomHeightCm) + " cm (" + String(roomHeightCm / 30.48, 1) + " ft)\n";
              pChar->setValue(reply.c_str());
              pChar->notify();
          }
        }
        else if (rxValue.indexOf("OTA_ON") != -1) {
          if (otaActive || otaConnecting || requestOtaStart) {
              pChar->setValue("[OTA] Already starting or active. Ignoring.\n");
              pChar->notify();
          } else {
              pChar->setValue("[OTA] Initiating... Powering down Radar & connecting to WiFi.\n");
              pChar->notify();
              requestOtaStart = true;
          }
        }
      }
    }
};

void startBLE() {
  BLEDevice::startAdvertising();
  isBleAdvertising = true;
  bleTurnedOnTime = millis();
}

void stopBLE() {
  BLEDevice::stopAdvertising();
  isBleAdvertising = false;
}

void sendBLENotification(const char* message) {
  if (deviceConnected) {
    pCharacteristic->setValue(message);
    pCharacteristic->notify();
  }
}

void goToSleep(bool infinite) {
  // If OTA is active or connecting, we can't sleep but we MUST still turn off the radar
  // to prevent the 30-second snapshot from spam-firing every loop iteration
  if (otaActive || otaConnecting) {
      if (isRadarPowered) {
          digitalWrite(RADAR_MOSFET_PIN, LOW);
          digitalWrite(FALL_LED_PIN, LOW);
          isRadarPowered = false;
      }
      return;
  }
  if (fallConfirmed) {
      radarTurnedOnTime = millis(); // Reset timer to prevent 1000Hz re-trigger loop while alarm active
      return;
  }

  digitalWrite(RADAR_MOSFET_PIN, LOW);
  digitalWrite(FALL_LED_PIN, LOW);
  isRadarPowered = false;

  if (deviceConnected) {
      // Fake Sleep Mode
      isFakeSleeping = true;
      infiniteFakeSleep = infinite;
      fakeSleepStartTime = millis();
      
      if (infinite) {
          // If sensor fusion warning will trigger, don't say room empty yet!
          if (!(pirSeenInSnapshot && micSeenInSnapshot)) {
              sendBLENotification("[SYS]: Room Empty. Going to Deep Sleep indefinitely...\n");
          }
      }
      else sendBLENotification("[SYS]: All OK. Going on standby for 60s...\n");
      // Auto log reset logic handled by timestamp tracking
      return; 
  }

  // Session logs reset handled by time, no need to reset vars
  
  if (isBleAdvertising) stopBLE();
  if (otaActive) { WiFi.disconnect(true); otaActive = false; }
  
  if (infinite) {
      // Infinite sleep: wake on PIR, MIC, or SYNC button
      uint64_t bitmask = (1ULL << PIR_WAKE_PIN) | (1ULL << MIC_WAKE_PIN) | (1ULL << SYNC_BUTTON_PIN);
      esp_sleep_enable_ext1_wakeup(bitmask, ESP_EXT1_WAKEUP_ANY_HIGH);
  } else {
      // Periodic 60s sleep: Allow Acoustic Impact THUD (MIC) and SYNC button to interrupt immediately!
      // (PIR walking motion is ignored to prevent battery drain in occupied room)
      uint64_t bitmask = (1ULL << SYNC_BUTTON_PIN) | (1ULL << MIC_WAKE_PIN);
      esp_sleep_enable_ext1_wakeup(bitmask, ESP_EXT1_WAKEUP_ANY_HIGH);
      esp_sleep_enable_timer_wakeup(PERIODIC_SLEEP_SEC * 1000000ULL);
  }
  
  pirTriggered = false;
  micTriggered = false;
  lastSleepTime = millis();
  
  esp_deep_sleep_start();
}

void powerOnRadar() {
  digitalWrite(RADAR_MOSFET_PIN, HIGH);
  digitalWrite(FALL_LED_PIN, HIGH);
  delay(1500);  // Allow C1001 1.5s to boot hardware & UART

  isRadarPowered = true;
  radarTurnedOnTime = millis();
  isFakeSleeping = false;
  
  // Reset fusion flags for this new session
  pirSeenInSnapshot = (currentTrigger == PIR_WALK_IN);
  micSeenInSnapshot = (currentTrigger == MIC_THUD);

  if (debugMode) {
      String onMsg = "[RADAR]: Boot. Trigger: ";
      switch(currentTrigger) {
        case PIR_WALK_IN: onMsg += "PIR\n"; break;
        case MIC_THUD:    onMsg += "MIC\n"; break;
        case PERIODIC_TIMER: onMsg += "Periodic 60s Timer\n"; break;
        default:          onMsg += "System\n"; break;
      }
      sendBLENotification(onMsg.c_str());
  }
}

float readBatteryVoltage() {
  int rawValue = analogRead(BATTERY_PIN);
  return (rawValue / 4095.0) * 3.3 * 2.0; 
}

void setup() {
  pinMode(RADAR_MOSFET_PIN, OUTPUT);
  pinMode(FALL_LED_PIN, OUTPUT);
  pinMode(PRESENCE_PIN, INPUT_PULLUP);
  pinMode(FALL_PIN, INPUT_PULLUP);
  pinMode(SYNC_BUTTON_PIN, INPUT_PULLDOWN);
  pinMode(PIR_WAKE_PIN, INPUT_PULLDOWN);
  pinMode(MIC_WAKE_PIN, INPUT_PULLDOWN);
  
  rtc_gpio_pulldown_en((gpio_num_t)PIR_WAKE_PIN);
  rtc_gpio_pulldown_en((gpio_num_t)MIC_WAKE_PIN);
  rtc_gpio_pullup_dis((gpio_num_t)MIC_WAKE_PIN);
  rtc_gpio_pulldown_en((gpio_num_t)SYNC_BUTTON_PIN);

  attachInterrupt(digitalPinToInterrupt(SYNC_BUTTON_PIN), syncButtonISR, RISING);
  attachInterrupt(digitalPinToInterrupt(PIR_WAKE_PIN), pirISR, RISING);
  attachInterrupt(digitalPinToInterrupt(MIC_WAKE_PIN), micISR, RISING);

  digitalWrite(RADAR_MOSFET_PIN, LOW);
  digitalWrite(FALL_LED_PIN, LOW);

  BLEDevice::init("Fall_Sensor_C1001_v4.22");
  pServer = BLEDevice::createServer();
  pServer->setCallbacks(new MyServerCallbacks());
  BLEService *pService = pServer->createService(SERVICE_UUID);
  pCharacteristic = pService->createCharacteristic(
                      CHARACTERISTIC_UUID,
                      BLECharacteristic::PROPERTY_READ | BLECharacteristic::PROPERTY_WRITE | BLECharacteristic::PROPERTY_NOTIFY
                    );
  pCharacteristic->setCallbacks(new MyCallbacks());
  pCharacteristic->addDescriptor(new BLE2902());
  pService->start();

  RadarSerial.begin(115200, SERIAL_8N1, RX_PIN, TX_PIN); 
  
  if (readBatteryVoltage() < 3.3) {
      batteryCritical = true;
  }
  
  esp_sleep_wakeup_cause_t wakeup_reason = esp_sleep_get_wakeup_cause();
  if (wakeup_reason == ESP_SLEEP_WAKEUP_EXT1) {
    uint64_t wakeup_pin_mask = esp_sleep_get_ext1_wakeup_status();
    if (wakeup_pin_mask & (1ULL << PIR_WAKE_PIN)) {
      currentTrigger = PIR_WALK_IN;
      lastPirLogTime = 0; // Force immediate log
    } else if (wakeup_pin_mask & (1ULL << MIC_WAKE_PIN)) {
      currentTrigger = MIC_THUD;
      lastMicLogTime = 0; // Force immediate log
    } else if (wakeup_pin_mask & (1ULL << SYNC_BUTTON_PIN)) {
      currentTrigger = MANUAL_SYNC;
      startBLE(); 
      return; // Skip radar for manual sync
    }
    powerOnRadar();
  } else if (wakeup_reason == ESP_SLEEP_WAKEUP_TIMER) {
      currentTrigger = PERIODIC_TIMER;
      powerOnRadar();
  } else {
      currentTrigger = BOOT;
      powerOnRadar();  
  }
}

void loop() {
  // --- Asynchronous Non-blocking OTA Handler & Absolute Freeze Guard ---
  if (otaActive || otaConnecting || requestOtaStart || otaDisconnectBlePending) {
      if (isRadarPowered) {
          digitalWrite(RADAR_MOSFET_PIN, LOW);
          digitalWrite(FALL_LED_PIN, LOW);
          isRadarPowered = false;
      }
      if (requestOtaStart) {
          requestOtaStart = false;
          isFakeSleeping = false;
          WiFi.mode(WIFI_STA);
          WiFi.begin(WIFI_SSID, WIFI_PASS);
          otaConnecting = true;
          otaConnectStartTime = millis();
      }
      if (otaConnecting) {
          if (WiFi.status() == WL_CONNECTED) {
              otaConnecting = false;
              ArduinoOTA.begin();
              otaActive = true;
              otaStartTime = millis();
              String ipMsg = "[OTA] Ready at: " + WiFi.localIP().toString() + " | Disconnecting BLE to save power...\n";
              sendBLENotification(ipMsg.c_str());
              otaDisconnectBlePending = true;
              otaDisconnectBleTime = millis();
          } else if (millis() - otaConnectStartTime > 15000) {
              otaConnecting = false;
              WiFi.disconnect(true);
              WiFi.mode(WIFI_OFF);
              sendBLENotification("[OTA] WiFi connection failed. Restoring normal mode.\n");
              powerOnRadar();
          }
          return;
      }
      if (otaDisconnectBlePending) {
          if (millis() - otaDisconnectBleTime > 1000) {
              otaDisconnectBlePending = false;
              BLEDevice::deinit(false);
              deviceConnected = false;
              isBleAdvertising = false;
          }
      }
      if (otaActive) {
          ArduinoOTA.handle();
          if (millis() - otaStartTime > 300000) {
              WiFi.disconnect(true);
              ESP.restart();
          }
      }
      return; // Absolute block — no PIR/MIC interrupts or radar logic run while OTA active!
  }

  if (isFakeSleeping) {
      // Flush ghost interrupts while asleep unless they actually break the sleep
      if (!infiniteFakeSleep && (millis() - fakeSleepStartTime > PERIODIC_SLEEP_SEC * 1000)) {
          pirTriggered = false;
          micTriggered = false;
          currentTrigger = PERIODIC_TIMER;
          powerOnRadar();
          return;
      }
      // During periodic (non-infinite) fake sleep, we just LOG the PIR/MIC triggers 
      // so the user can see them, but we DO NOT wake the radar up.
      // Only the 60-second timer will actually wake the radar.
      if (!infiniteFakeSleep) {
          if (pirTriggered) {
              pirTriggered = false;
              if (deviceConnected && (millis() - lastPirLogTime > DEBOUNCE_COOLDOWN)) {
                  sendBLENotification("[SYS]: PIR Triggered! (Ignored during 60s sleep)\n");
                  lastPirLogTime = millis();
              }
          }
          if (micTriggered) {
              micTriggered = false;
              if (deviceConnected && (millis() - lastMicLogTime > DEBOUNCE_COOLDOWN)) {
                  sendBLENotification("[SYS]: MIC Triggered! (Ignored during 60s sleep)\n");
                  lastMicLogTime = millis();
              }
          }
      } else {
          // Infinite fake sleep: PIR/MIC CAN break it (room was empty, new activity)
          if (pirTriggered) {
              pirTriggered = false;
              micTriggered = false;
              currentTrigger = PIR_WALK_IN;
              powerOnRadar();
              return;
          }
          if (micTriggered) {
              micTriggered = false;
              pirTriggered = false;
              currentTrigger = MIC_THUD;
              powerOnRadar();
              return;
          }
      }
      return; // Skip rest of loop while in standby
  }

  // Live Interrupt Handling (with PIR cooldown to prevent wake/sleep loops)
  if (pirTriggered) {
      pirTriggered = false;
      // Ignore PIR if we just woke up less than 5s ago (residual heat)
      if (millis() - lastSleepTime < PIR_COOLDOWN_MS && lastSleepTime > 0) {
          // Silently discard — PIR is still seeing residual heat from before sleep
      } else {
          pirSeenInSnapshot = true;
          if (deviceConnected && (millis() - lastPirLogTime > DEBOUNCE_COOLDOWN)) {
              sendBLENotification("[SYS]: PIR Triggered!\n");
              lastPirLogTime = millis();
          }
          if (!isRadarPowered) { 
              currentTrigger = PIR_WALK_IN; 
              powerOnRadar(); 
          }
      }
  }

  if (micTriggered) {
      micTriggered = false; 
      micSeenInSnapshot = true;
      if (deviceConnected && (millis() - lastMicLogTime > DEBOUNCE_COOLDOWN)) {
          sendBLENotification("[SYS]: MIC Triggered!\n");
          lastMicLogTime = millis();
      }
      if (!isRadarPowered) { 
          currentTrigger = MIC_THUD; 
          powerOnRadar(); 
      }
  }

  if (requestRadarPowerOn && !isRadarPowered) {
      requestRadarPowerOn = false;
      currentTrigger = MANUAL_SYNC;
      powerOnRadar();
  }

  if (syncButtonPressed) {
      syncButtonPressed = false;
      if (fallConfirmed) {
          fallConfirmed = false;
          sustainedMoveStartTime = 0;
          digitalWrite(FALL_LED_PIN, HIGH);
          sendBLENotification("[FALL] Cleared: Manual Sync Button pressed.\n");
      }
      if (!isBleAdvertising && !deviceConnected) {
          startBLE();
      }
  }

  if (!isRadarPowered && isBleAdvertising && !deviceConnected) {
      if (millis() - bleTurnedOnTime > 60000) { goToSleep(true); }
  }

  if (deviceConnected && !batteryReported && (millis() - bleTurnedOnTime > 1500)) {
      float battV = readBatteryVoltage();
      String battMsg = "[SYS] Battery: " + String(battV, 2) + "V\n";
      if (batteryCritical) battMsg += "[WARN]: BATTERY CRITICAL (< 3.3V)!\n";
      sendBLENotification(battMsg.c_str());
      batteryReported = true;
  }

  // --- C1001 Radar Logic (Pins + UART Fallback) ---
  if (isRadarPowered) {
      
      int rawPin25 = digitalRead(PRESENCE_PIN);
      int rawPin26 = digitalRead(FALL_PIN);
      
      bool uartPresence = (hu.dmHumanData(hu.eExistence) == 1);
      int fallState = hu.getFallData(hu.eFallState);  // Cache result — calling twice corrupts UART buffer!
      bool uartFall = (fallState == 1 || fallState == 2);
      
      // Hardware Pin presence: GPIO fast-path for early exit (same pattern as LD2410)
      bool hardwarePresence = (rawPin25 == HIGH);
      bool hardwareFall = (rawPin26 == HIGH);
      
      bool presenceDetected = hardwarePresence || uartPresence;
      bool fallDetected = hardwareFall || uartFall;
      
      uint16_t dist = 0;
      if (uartPresence) { 
          dist = hu.dmHumanData(hu.eMotionHorizontalDistance); 
          if (dist == 0) {
              dist = hu.smHumanData(hu.eHumanDistance); // direct line-of-sight distance from ceiling
          }
      }

      // Check if target is at floor level (e.g. 9ft room: 274cm - 45cm = 229cm to 274cm + 35cm = 309cm)
      bool isAtFloorLevel = false;
      if (presenceDetected && dist > 0) {
          if (dist >= (roomHeightCm - floorToleranceCm) && dist <= (roomHeightCm + 35)) {
              isAtFloorLevel = true;
          }
      }

      // --- Posture Transition Tracking (Silent Fall / Gradual Collapse Detection) ---
      // Track when person was last at standing height (well above floor)
      if (!isAtFloorLevel && presenceDetected && dist > 0 && dist < (roomHeightCm - floorToleranceCm)) {
          lastStandingDistCm = dist;
          lastStandingTime = millis();
      }
      
      // Detect rapid standing-to-floor transition (gradual collapse)
      if (isAtFloorLevel && lastStandingDistCm > 0 && lastStandingTime > 0) {
          unsigned long transitionTime = millis() - lastStandingTime;
          if (transitionTime > 0 && transitionTime < 30000) {  // Standing-to-floor in < 30s
              if (!fallConfirmed) {
                  fallConfirmed = true;
                  sustainedMoveStartTime = 0;
                  String msg = "ALERT: FALL DETECTED (Gradual Posture Collapse in " + String(transitionTime/1000) + "s)!\n";
                  sendBLENotification(msg.c_str());
              }
          }
      }
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

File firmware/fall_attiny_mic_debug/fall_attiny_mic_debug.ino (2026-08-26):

// ATtiny85 MIC Debug Firmware
// PURPOSE: Flash MIC_OUT (PB0) LED to visually confirm whether the ATtiny85
//          is seeing the MIC's digital output transitions.
//
// WIRING FOR DEBUG:
//   Connect an LED + 330Ω resistor from PB0 (MIC_OUT_PIN) to GND.
//   Or just observe the ESP32's Pin 4 line — it will pulse on every MIC detection.
//
// BEHAVIOR:
//   - On MIC state change: 3 rapid blinks (100ms each) on PB0
//   - On PIR trigger: 1 long blink (500ms) on PB2 (normal)
//   - Between triggers: PB3 (onboard LED on some Digispark boards) shows MIC_IN raw state
//
// After debugging, reflash with the production fall_attiny_v1.ino

#include <avr/sleep.h>
#include <avr/interrupt.h>

// --- HARDWARE PINS ---
#define MIC_OUT_PIN  0  // PB0: Sends wake pulse to ESP32 Pin 4
#define PIR_IN_PIN   1  // PB1: PCINT1 (From PIR module)
#define PIR_OUT_PIN  2  // PB2: Sends wake pulse to ESP32 Pin 13
#define LED_DBG_PIN  3  // PB3: Onboard LED (Digispark Model B) — used as MIC level mirror
#define MIC_IN_PIN   4  // PB4: PCINT4 (From 4-Pin Mic DO pin)

bool lastPirState = LOW;
bool lastMicState = LOW;
volatile bool wakeFlag = false;

ISR(PCINT0_vect) {
  wakeFlag = true;
}

void blinkFast(int pin, int count) {
  for (int i = 0; i < count; i++) {
    digitalWrite(pin, HIGH);
    delay(100);
    digitalWrite(pin, LOW);
    delay(100);
  }
}

void setup() {
  pinMode(PIR_OUT_PIN, OUTPUT);
  pinMode(MIC_OUT_PIN, OUTPUT);
  pinMode(LED_DBG_PIN, OUTPUT);  // Debug LED
  
  digitalWrite(PIR_OUT_PIN, LOW);
  digitalWrite(MIC_OUT_PIN, LOW);
  digitalWrite(LED_DBG_PIN, LOW);

  pinMode(PIR_IN_PIN, INPUT);
  pinMode(MIC_IN_PIN, INPUT_PULLUP);  // Same as production: internal pull-up for clean idle HIGH

  // Configure Pin Change Interrupts for PIR and MIC
  GIMSK |= (1 << PCIE);    
  PCMSK |= (1 << PCINT1);  // PIR
  PCMSK |= (1 << PCINT4);  // MIC

  set_sleep_mode(SLEEP_MODE_PWR_DOWN);
  
  // Startup blink: 5 rapid flashes on MIC_OUT to confirm firmware is loaded
  blinkFast(MIC_OUT_PIN, 5);
}

void loop() {
  bool currentPirState = digitalRead(PIR_IN_PIN);
  bool currentMicState = digitalRead(MIC_IN_PIN);

  // --- Mirror MIC_IN raw level to debug LED ---
  // This lets you see the LIVE state of the MIC digital output
  // If the LED stays solid ON or solid OFF and never changes during sound,
  // the MIC module's HIGH isn't crossing ATtiny85's VIH threshold (~2.6V @ 5V VCC)
  digitalWrite(LED_DBG_PIN, currentMicState);

  // --- PIR LOGIC (normal) ---
  if (currentPirState == HIGH && lastPirState == LOW) {
    digitalWrite(PIR_OUT_PIN, HIGH);
    delay(50); 
    digitalWrite(PIR_OUT_PIN, LOW);
  } 
  
  // --- MIC LOGIC (debug enhanced) ---
  if (currentMicState != lastMicState) {
    // Normal wake pulse to ESP32
    digitalWrite(MIC_OUT_PIN, HIGH);
    delay(50);
    digitalWrite(MIC_OUT_PIN, LOW);
    
    // DEBUG: 3 rapid blinks on MIC_OUT to visually confirm detection
    delay(100);
    blinkFast(MIC_OUT_PIN, 3);
    
    // 500ms acoustic debounce
    delay(500); 
  }

  lastPirState = currentPirState;
  lastMicState = digitalRead(MIC_IN_PIN); 

  // --- SLEEP ---
  sleep_enable();
  noInterrupts();
  GIFR = (1 << PCIF); 
  interrupts();
  sleep_cpu();
  sleep_disable();
}

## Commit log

2026-08-26 Initial commit: Fall Sensor System (v4.20 Firmware, KiCad PCB Hardware, Android App & Docs)
    [fall_sensor-B_Cu.gbr, fall_sensor-B_Mask.gbr, fall_sensor-B_Silkscreen.gbr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]
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2026-08-26 Add combined Front+Back A4 PCB print sheet (1:1 scale) and A4 printable schematic PDF
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2026-09-01 Update hardware: Implement optimized 5-capacitor Through-Hole design (Option A) with 0 DRC errors, new Gerbers, and A4 print sheets
    [fall_sensor-B_Cu.gbl, fall_sensor-B_Mask.gbs, fall_sensor-B_Silkscreen.gbo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]
2026-09-02 Update PCB physical outlines: AM312 PIR 22x20mm breakout, LM2596 21.5mm width, TP4056 18mm width, and regenerate all A4 PDFs and Gerbers
    [fall_sensor.kicad_pcb, fall_sensor.kicad_sch]
2026-09-02 Add 3D printed wall-mount enclosure stream: STL models (Base & Lid), OpenSCAD parametric code, Blender project, renders, and fabrication guide
    [fall_sensor_enclosure.blend, fall_sensor_enclosure.scad, fall_sensor_enclosure_base.stl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]
2026-09-02 Comprehensive 4-stream update: Firmware v4.23 (Silent Fall fix), Enclosure solid lid & corrected apertures, and clean symmetric PIR footprint
    [fall_sensor.kicad_pcb, fall_sensor_enclosure.blend, fall_sensor_enclosure.scad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]
2026-09-02 Hardware: Flip PIR1 footprint horizontally into open PCB space (clearing C4/C8, 0 overlaps)
    [fall_sensor.kicad_pcb]
2026-09-02 Enclosure: Update PIR dome aperture to (84.0, 69.2) to match right-flipped PIR footprint
    [fall_sensor_enclosure.blend, fall_sensor_enclosure.scad, fall_sensor_enclosure_base.stl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]
2026-09-02 Export 3D STEP models (full assembly and board dummy) and 3D printable PCB dummy STL for enclosure test-fitting
    [fall_sensor.step, fall_sensor_board_dummy.step, fall_sensor_full_assembly.step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]
2026-09-03 Enclosure v2.0: Square form factor (107x111mm) with integrated 18650 battery compartment and wire notch
    [fall_sensor_enclosure.blend, fall_sensor_enclosure.scad, fall_sensor_enclosure_base.stl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]
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2026-09-03 Enclosure v2.1: Verified USB-C port and power switch on left wall matching TP4056 board orientation, opposite from C1001 Radar
    [fall_sensor_enclosure.blend, fall_sensor_enclosure.scad, fall_sensor_enclosure_base.stl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]
2026-09-03 Enclosure Renders: Fix studio depth clipping, add Track-To auto-framing, and export exploded assembly view
    [fall_sensor_enclosure.blend, fall_sensor_enclosure_base.stl, fall_sensor_enclosure_lid.stl]
2026-09-03 Enclosure: Fix camera math framing with generous margins and restore clean lid corner
    [fall_sensor_enclosure.blend, fall_sensor_enclosure_base.stl, fall_sensor_enclosure_lid.stl]
2026-09-03 Enclosure Renders: Zoom in Hero and Exploded views by 25% and refresh enclosure_preview with zero cropping
    [fall_sensor_enclosure.blend, fall_sensor_enclosure_base.stl, fall_sensor_enclosure_lid.stl]
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2026-09-03 PCB Prints: Fix 10% dimension error in merged A4 sheet by vector-clipping exact 100x80mm CAD boundaries and isolating 10mm radar overhang
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2026-09-03 Cross-Stream Alignment: Shift PIR to X=137mm, add 79.5mm battery retaining wall, expand enclosure to 116.8x110.8mm square, and add automated regression test suite
    [fall_sensor.kicad_pcb, fall_sensor.kicad_sch, fall_sensor_enclosure.blend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]
2026-09-03 Hardware & Layout Audit: Shift PIR to X=139.5mm (0 courtyard overlap with MIC), add AM312_PIR_Square22x20 footprint, lock C1 to battery rail, and align enclosure lid
    [fall_sensor.kicad_pcb, fall_sensor.kicad_sch, fall_sensor_enclosure.blend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]
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2026-09-03 CAD & Enclosure: Restore two-tone color scheme (graphite base, white lid, dark studio floor) with Track-To centered camera framing
    [fall_sensor_enclosure.blend, fall_sensor_enclosure_base.stl, fall_sensor_enclosure_lid.stl]
2026-09-03 CAD Renders: Match light studio background with studio/wallmount views, eliminate cavity shadow artifact in exploded view, and elevate hero framing
    [fall_sensor_enclosure.blend]
2026-09-03 CAD Renders: Darkened studio background throughout (0.68, 0.71, 0.75) for crisp white lid separation across all 4 views
    [fall_sensor_enclosure.blend]
2026-09-03 CAD & Enclosure: Limit battery cradle wall to 79.5mm, leaving upper right space 100% open for PIR sensor extension; re-render all 4 views with full framing
    [fall_sensor_enclosure.blend, fall_sensor_enclosure_base.stl, fall_sensor_enclosure_lid.stl]
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2026-09-03 CAD & Enclosure: Re-rendered all 4 views with locked darker studio background (0.68, 0.71, 0.75) and pulled back camera zoom by 12-14% on Studio and Wallmount views to eliminate cropping
    [fall_sensor_enclosure.blend, fall_sensor_enclosure_base.stl, fall_sensor_enclosure_lid.stl]
2026-09-03 CAD & Enclosure: Removed SPDT power switch cutout (header pin jumper used on PCB); verified PIR and MIC exact PCB coordinate alignment down to 0.01mm
    [fall_sensor_enclosure.blend, fall_sensor_enclosure_base.stl, fall_sensor_enclosure_lid.stl]
2026-09-05 CAD & Enclosure: Added 4-corner downward PCB clamping tabs (3.9mm height) to lid to rigidly clamp PCB against base shelf posts with zero rattle
    [fall_sensor_enclosure.blend, fall_sensor_enclosure_base.stl, fall_sensor_enclosure_lid.stl]
2026-09-05 CAD & Enclosure: Flipped lid open in Studio Side-by-Side view to clearly reveal the 4 corner PCB clamping tabs, alignment lip, and internal radar pocket
    [fall_sensor_enclosure.blend, fall_sensor_enclosure_base.stl, fall_sensor_enclosure_lid.stl]
2026-09-07 CAD & Enclosure: Added 4-corner solid lid screw boss pillars matching base bosses; verified M3x25mm CSK screw engagement and updated all deliverables
    [fall_sensor_enclosure.blend, fall_sensor_enclosure_base.stl, fall_sensor_enclosure_lid.stl]
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2026-09-07 fix(cad,docs): optimize PCB clamping zones, center USB-C port, update docs and regen exports
    [fall_sensor_enclosure.blend, fall_sensor_enclosure.scad, fall_sensor_enclosure_base.stl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]
2026-09-07 feat(enclosure): export true 1:1 PCB test-fit STL with all 186 through-holes from KiCad
    [fall_sensor_pcb_dummy.stl]
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2026-09-18 feat(hardware,enclosure): PCB corner chamfer, relocated battery pads, 2-page 1:1 PDF, centered wall hooks, and perfboard wiring guide
    [fall_sensor-B_Courtyard.gbr, fall_sensor-B_Cu.gbl, fall_sensor-B_Mask.gbs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]
2026-09-18 fix(hardware): correct U7 LM2596 bounding box and label placement inside PCB boundary in 1:1 printable PDF
2026-09-18 feat(hardware,enclosure): shift PIR1 by +0.90mm for safe board edge margin, update lid aperture, and regenerate exports
    [fall_sensor-B_Courtyard.gbr, fall_sensor-B_Cu.gbl, fall_sensor-B_Mask.gbs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]
2026-09-18 feat(enclosure,template): synchronize U7 support shelf and Ledge 1 to guarantee 100% pin-free clearances
    [fall_sensor_enclosure.blend, fall_sensor_enclosure_base.stl, fall_sensor_enclosure_lid.stl]
2026-09-18 feat(enclosure,template): add built-in 14x14x6.8mm ESP32 contact boss to lid for roof-mount overhead constraint
    [fall_sensor_enclosure.blend, fall_sensor_enclosure_base.stl, fall_sensor_enclosure_lid.stl]
2026-09-19 feat(enclosure): optimize to 28mm slim ceiling profile with flared 45-deg PIR and MIC apertures
    [fall_sensor_enclosure.blend, fall_sensor_enclosure_base.stl, fall_sensor_enclosure_lid.stl]
2026-09-19 feat(enclosure): add PIR 2.4mm dome protrusion pocket, LED diffuser flare, and Sync button chamfer
    [fall_sensor_enclosure.blend, fall_sensor_enclosure_base.stl, fall_sensor_enclosure_lid.stl]
2026-09-19 fix(enclosure): calibrate USB-C cutout elevation to 14.5mm for TP4056 on male header standoffs, rebuild STLs and renders
    [fall_sensor_enclosure.blend, fall_sensor_enclosure_base.stl, fall_sensor_enclosure_lid.stl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]
